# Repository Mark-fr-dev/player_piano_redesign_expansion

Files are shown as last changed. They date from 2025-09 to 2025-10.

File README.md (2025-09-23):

Player-Piano (FreeCAD Redesign and extension)

## Overview
This project is a **redesign of my earlier player-piano prototype**, moving from a wooden/acrylic build into a **parametric FreeCAD model** suitable for 3D printing.  
The aim is to create a **stable, modular frame** that can drive ~44 keys of a roll-up piano keyboard without “walking” across the surface. Later I plan to run it from a raspbery pi, which will ultimately be controlled via an AWS enabled server from an SAP HANA database.

- ✅ Open-source, parametric CAD design in **FreeCAD**  
- ✅ Modular approach: ~1 octave per frame section, bolted together  
- ✅ Arduino-driven servos (firmware in [separate repo](https://github.com/yourname/arduino-repo))  
- ✅ Documentation of design process via daily **lab notes**

---

## Project Goals
- Eliminate instability of the first prototype (prevent frame “walking”).  
- Create a **printable modular system** (1-octave units, chained to 44 keys).  
- Make the design **parameter-driven** (adjustable key pitch, frame spacing, servo layout).  
- Improve aesthetics and reproducibility (cleaner than the prototype).  

---

## Repository Structure
freecad/ # .FCStd parametric design files
stl/ # STL exports for 3D printing
notes/ # Daily lab notes in Markdown
images/ # Screenshots, diagrams, renders
README.md # Project overview (this file)

---

## Parameters (current baseline)
These are defined in a FreeCAD **Spreadsheet (Params)** and drive the master sketches:

| Parameter | Value | Notes |
|---|---|---|
| `white_pitch` | 23 mm | White key spacing |
| `octave_width` | 161 mm  | 7 × white_pitch |
| `piano_depth` | 161 mm  | Depth of active key area |
| `black_pitch_2` | 28 mm | 2-black-key group width |
| `black_pitch_3` | 27 mm | 3-black-key group width |
| `inter_black_pitch` | 39.5 mm | Gap between black groups |
| `full_frame_depth` | 220 mm  | Total module depth |
| `full_frame_height` | 180 mm  | Total module height |
| `servo_y_spacing` | 76.4 mm | Servo row spacing |

(See [/notes](notes/) for full parameter tables and daily updates.)

---

## Build Concept
- **Frame**: Each octave = base plate (XY) + side cheeks (YZ), joined by bolts/dowels.  
- **Servo bar**: Spanning between cheeks, aligned to white/black key offsets.  
- **Modularity**: 4 modules chained → 44 notes total.  
- **Fasteners**:  
  - Z-direction bolts: clamp stacked frame layers.  
  - X-direction bolts: join octaves side-to-side.  

---

## Previous Prototype
The original player-piano prototype was built using **wood and perspex, with Fusion 360 CAD**.  
Documentation (sketches and videos) is preserved in the repo: [player-piano (prototype)](https://github.com/yourname/player-piano).  

---

## Firmware
Servo driving software is maintained separately:  
👉 [arduino-player-piano](https://github.com/yourname/arduino-repo)  

---

## Progress Tracking
- Daily lab notes: [/notes](notes/)  
- Screenshots/renders: [/images](images/)  

---

## License
[MIT](LICENSE) — free to use, modify, and build upon.

---
=======
# player_piano_redesign_expansion
Redesign of my piano-player for 3D printing, raspberry pie and online song selection

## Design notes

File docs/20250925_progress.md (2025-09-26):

ChatGPT said:

Yes 👍 — I can see a few key things from our exchanges today that didn’t make it into your notes but would strengthen them. Here’s a refined draft with those items included:

# Piano Player Project — Daily Lab Notes
Date: 2025-09-25
Module: Piano bed and servo mounting structures

## Progress Today
- Reworked Params spreadsheet for tidiness; grouped parameters by category (keys, frame, servos, fasteners).
- Confirmed all parameters have aliases, so reordering won’t break references.
- Added horizontal positioning (dowel) holes to the "piano_bed" for alignment.
- Adjusted overall bedplate dimensions to fit within Prusa i3 build volume (250 × 210 × 210).
- Captured servo dimensions for SG90 profile and began setting up servo mounting geometry.
- Started decreasing material volume by adding pockets into the piano bed to reduce print time and filament cost.
- Started design of servo base plate, initially 3 mm thick, with awareness of balancing stiffness vs. print time.
- Discussed print-time/material tradeoffs (full plate ≈ 9 h vs ribbed/segmented ≈ 4–5 h).
- Confirmed workflow preference: add fillets as 3D features later in the tree, not inside sketches, for efficiency and robustness.
- Learned multiple ways to array cutouts (Sketcher Array, Part Design Linear Pattern, Draft Array).

## Next Steps
- Add vertical locating holes for stacking stability between layers.
- Test 3 mm servo base plate with ribs or flanges instead of pure thickness to save print time.
- Create parametric array of servo cutouts driven by `white_pitch`.
- Produce small coupon print (bolt + dowel cluster) to validate tolerances (~0.2 mm).
- Add fillet features at the end of body history for edges/pads.

## Design Notes (high-level rationale)
- One global Params spreadsheet will be used, with grouping by function (Keys, Frame, Servos, Fasteners). Local part-specific values can be added in separate sections.
- Dowels handle positioning, bolts handle clamping; clear separation of function improves assembly repeatability.
- Large flat plates risk long print times and wasted filament; ribbing strategy adopted to reduce cost/time while maintaining stiffness.
- Servo mounting will be split into two servo bars (white-key servos, black-key servos), both mounted to the servo base plate.
- Fillets applied at the feature level for cleaner sketches and easier future edits.

## File Updates
- Params.FCStd (spreadsheet restructured, all aliases set)
- Piano_bed.FCStd (added dowel holes, initial volume-reduction pockets)
- Servo_base_plate.FCStd (initial sketch, 3 mm thickness)

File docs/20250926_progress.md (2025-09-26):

# Piano Player Project — Daily Lab Notes
Date: 2025-09-25
Module: Piano_bed, Servo_plate, White_servo_bar

## Progress Today
- Completed lightening holes in the Piano_bed (circular array, parametric diameter/spacing).  
  → Purpose: reduce material volume and print time while maintaining stiffness.  
- Finalized horizontal and vertical bolt holes, dowel positioning holes, and push pads on the Piano_bed.  
- Completed Servo_plate with:  
  - Shaft holes for push rods.  
  - Mount holes and bosses for alignment.  
  - Servo mount tab slots sized for SG90 geometry.  
- Began White_servo_bar design:  
  - Captured key pitch from global parameters.  
  - Established initial spacing for servo cutouts.  
- Considered trade-off between custom lightening pockets (triangles) vs. simpler arrays (circles/rectangles) → settled on circular cutouts for efficiency and strength.  
- Reviewed FreeCAD workflow for arrays (Sketcher array vs Part Design Linear Pattern).  
- Confirmed strategy to keep sketches simple, with fillets and chamfers applied later as features.

## Next Steps
- Finish White_servo_bar geometry (servo slot dimensions, mounting holes).  
- Create Black_servo_bar with parametric offset relative to white keys.  
- Add vertical locating holes to Piano_bed for module stacking.  
- Test 3 mm plate + lightening holes vs ribbed reinforcement for print time/strength balance.  
- Export small coupon print (servo slot + boss + dowel) to test tolerances before full module print.

## Design Notes (high-level rationale)
- Lightening holes: chosen as circular for simplicity, robustness, and faster sketch/solve times compared to triangular pockets.  
- Bosses added to Servo_plate to strengthen mounting points for M5 screws.  
- Servo tab slots dimensioned from captured SG90 geometry (servo_width, servo_depth).  
- Servo mounting structure divided into White_servo_bar and Black_servo_bar to match key grouping, simplifying assembly and reducing print failures.  
- Parameter spreadsheet updated to drive new features consistently (bolt diameters, servo offsets, pitch).  

## File Updates
- Piano_bed.FCStd (added lightening holes, dowels refined).  
- Servo_plate.FCStd (completed shaft holes, bosses, tab slots).  
- White_servo_bar.FCStd (initial sketch started).

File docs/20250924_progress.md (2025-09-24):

# Piano Player Project — Daily Lab Notes
Date: 2025-09-24
Module: Piano Bed (1 Octave)

## Progress Today
- Designed the bedplate for one octave.
- Integrated horizontal and vertical bolt holes for fastening modules together.
- Added horizontal locating holes (dowels) for precise alignment.
- Added reinforced pads to transmit the piano push forces directly into the table surface, reducing stress on the frame.
- Confirmed overall geometry fits FreeCAD parametric structure.

## Next Steps
- Add vertical locating holes (to align stacked parts or cheek frames).
- Create white_key_bar and black_key_bar
- Create servo_base
- Work on the servo plate on which all the servos will be mounted

## Design Notes (high-level rationale)
- Pads: Avoid frame "walking" by transferring force vertically downward into the table.
- Dowels: Ensure repeatable alignment across octaves. Bolts handle clamping, dowels handle positioning.
- Dual fastening (horizontal + vertical): Supports both side-to-side chaining of octaves and vertical stacking of layers.
- Structure left simple for now — honeycomb infill will be handled by the slicer, not modeled in FreeCAD.

## File Updates
- Piano_bed.FCStd → new baseplate geometry.
- Design notes document updated with part-level rationale.

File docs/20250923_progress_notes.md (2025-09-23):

# 🎹 Piano Player Project — Lab Notes
**Date:** 2025-09-23  
**Author:** Mark de Villiers  

---

## Objective
Redesign the piano player mechanism to be **more stable** (prevent “walking” on the rubber keyboard), improve appearance, and prepare for a **3D-printed modular version**. The long-term aim is to achieve a rigid, reliable structure that can be printed at low cost and assembled in modules (≈1 octave each).

---

## Activities Today
- **Transitioned CAD tools**  
  - Began learning **FreeCAD** as an alternative to Fusion 360 (too expensive).  
  - Learned FreeCAD basics: creating sketches, pads, referencing planes, and capturing geometry.  

- **Captured baseline geometry**  
  - Modeled the prototype piano player frame (current dimensions).  
  - Confirmed the approximate overall size; unlikely to reduce footprint significantly, but improvements in **rigidity and aesthetics** are achievable.  

- **Parameterization**  
  - Created initial design parameters for keys, frame, and servos.  
  - Verified octave width, white/black key spacing, and depth relations.  

- **Next steps**  
  - Integrate these parameters into a FreeCAD **Spreadsheet** for parametric design.  
  - Begin modular design (1-octave frame with side cheeks, servo bar, and base plate).  
  - Test ShapeBinders to propagate master sketches into Bodies.  

---

## Parameters Defined
| Parameter | Value | Notes |
|---|---|---|
| `white_pitch` | 23 mm | White key spacing |
| `octave_width` | 161 mm | 7 × white_pitch |
| `piano_depth` | 161 mm | Depth of piano key area |
| `key_depth` | 131 mm | Active depth of white keys |
| `black_pitch_2` | 28 mm | Spacing for 2-black-key group |
| `black_pitch_3` | 27 mm | Spacing for 3-black-key group |
| `inter_black_pitch` | 39.5 mm | Gap between black key groups |
| `black_key_width` | 12 mm | Nominal width of black key |
| `white_key_width` | 20.5 mm | Nominal width of white key |
| `black_key_depth` | 80 mm | Depth of black key |
| `full_frame_depth` | 220 mm | Total depth of module |
| `full_frame_height` | 180 mm | Total height of module |
| `edge_offset` | 15 mm | Bolt hole offset |
| `rubber_height_clearance` | 15 mm | Rubber key + 5 mm clearance |
| `base_thickness` | 20 mm | Printed base plate |
| `shaft_length` | 125 mm | Servo shaft length requirement |
| `servo_travel` | 10 mm | Actuator stroke |
| `top_thickness` | 5 mm | Printed top plate |
| `servo_y_spacing` | 76.4 mm | Spacing between servo rows |

---

## Reflections
- FreeCAD is different from Fusion 360 but already feels workable for this project.  
- The prototype size may stay similar, but **parametric modeling** will let me refine structure, tolerances, and servo alignment.  
- The focus now is **rigidity + modularity** (1-octave units that bolt together cleanly).  

---

## Next Steps
- Build **Spreadsheet (Params)** in FreeCAD with the values above.  
- Create **master sketches** (XY for footprint, ZY for cheeks, bolt hole references).  
- Experiment with **ShapeBinders** to reuse sketches across Bodies.  
- Print a **test plate** with bolt holes to check tolerances (M3/M5, dowels).  
- Draft servo bar design: use `servo_y_spacing` + `white_pitch` to test array of cutouts.  

---

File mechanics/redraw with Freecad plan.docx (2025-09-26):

1. Create a new document & structure

- Open FreeCAD → File → New.
- In Part Design workbench:
  - Create a Part container (name: Piano_ModularFrame).
  - Inside, create a Body (name: Master_Body).
  - This will hold your master geometry (keyboard outline, bolt pattern, reference planes).

2. Master sketch (parametric skeleton)

- In Master_Body, create a new Sketch on the XY plane.
- Draw:
  - A rectangle for the keyboard footprint per octave (about 164 mm × ~120 mm deep).
  - Add construction lines for note spacing (12 equal divisions along width).
  - Add 2–3 circles outside edges → bolt holes for module joining.
- Constrain dimensions with named parameters:
  - octave_width = 164 mm
  - depth = 120 mm
  - bolt_spacing = 80 mm (Tip: put them in the Spreadsheet workbench, link dimensions → makes edits easy later).

3. Derive module bodies

- For each part (side rail, top rib, actuator bar, clamp jaws), create a new Body.
- Use ShapeBinder to pull in the master sketch references (keyboard outline, bolt holes).
- Build features relative to these, so changes propagate.

Examples:

- Side Rail:
  - Sketch profile (L-shaped or ribbed beam) along the side.
  - Pad to full depth.
- Top Plate / Rib:
  - Sketch on XY → pad 5–6 mm.
  - Add cutouts for servo bar and wiring.
- Servo Bar:
  - Long rectangular beam across module width.
  - Add pockets for servos (20×12 mm typical for micro SG90 class).
- Clamps:
  - Small pads on the side edges of the footprint rectangle.
  - Sketch → pad up → fillet corners.

4. Assembly interfaces

- On each side face of the module, extrude small alignment bosses (Ø 6 mm).
- Matching recess on the opposite side.
- Add 2× through bolt holes (M5 clearance = 5.5 mm) per side.
- This ensures rigid alignment when bolting modules together.

5. Printing considerations

- Split tall parts (side cheeks) if they exceed your 210 mm Z.
- Design ribs and cutouts so modules are light but stiff.
- Add nut traps for bolts:
  - M3/M5 hex pockets undersized by ~0.2 mm.
- Tolerances:
  - Sliding fit: +0.3 mm clearance.
  - Alignment pins: oversize hole by +0.1–0.2 mm, ream after printing.

6. Parametric array & partial module

- Use Draft Array or Assembly4 workbench to copy the module 6×.
- For the last module (44 notes total), suppress 4 keys (partial).

7. Export for print

- Select each Body → File → Export → STL.
- Slice in PrusaSlicer. Print test pieces at low infill (10–15%) first to confirm fits.

✅ Suggested module contents

Each octave module includes:

- Frame (side rails + top/bottom ribs + bolt interface)
- Actuator bar with servo pockets (12 max)
- Clamps to hold roll-up piano edge
- Cable channels at rear
- Alignment bosses + bolt holes for chaining

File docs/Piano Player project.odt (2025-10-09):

SAP HANA project

# Piano electronics

## Get existing system working again

## Consider if upgraded PCB is worth the effort?

### Can fix jitter problems?

## redesign?

## Reassemble

## Re-fault check

# Raspberry Pi

## New software/packages that can do the following:

## Send midi sigs to Arduino

## Get data from arduino? What data? How?

## Get full songs from HANA?

## Send data to HANA, how? Which data?

# Piano mechanics

## Full redesign for 3D manufacture

## Remove 44 servos from existing half player

## Consider installing 44 new servos for complete system

# Piano software (Arduino Mega)

## Software will definitely need to be rewritten/modified

## Once the mechanics and electronics are stable once more

# HANA DB

## Send data to raspberry pi

## Recieve data from pi

# Simple website

## request songs to play on player

## View livestream of 1 or 2 cameras as the song plays.

## Display HANA data in a meaningful way

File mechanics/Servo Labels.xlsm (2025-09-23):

PN | 2 | PN | 25 | PN | 40 | PN | 2 | PN | 25 | PN | 40
SVN | 0 | SVN | 15 | SVN | 30 | SVN | 0 | SVN | 15 | SVN | 30
PN | 3 | PN | 26 | PN | 41 | PN | 3 | PN | 26 | PN | 41
SVN | 1 | SVN | 16 | SVN | 31 | SVN | 1 | SVN | 16 | SVN | 31
PN | 4 | PN | 27 | PN | 42 | PN | 4 | PN | 27 | PN | 42
SVN | 2 | SVN | 17 | SVN | 32 | SVN | 2 | SVN | 17 | SVN | 32
PN | 5 | PN | 28 | PN | 43 | PN | 5 | PN | 28 | PN | 43
SVN | 3 | SVN | 18 | SVN | 33 | SVN | 3 | SVN | 18 | SVN | 33
PN | 6 | PN | 29 | PN | 44 | PN | 6 | PN | 29 | PN | 44
SVN | 4 | SVN | 19 | SVN | 34 | SVN | 4 | SVN | 19 | SVN | 34
PN | 7 | PN | 30 | PN | 45 | PN | 7 | PN | 30 | PN | 45
SVN | 5 | SVN | 20 | SVN | 35 | SVN | 5 | SVN | 20 | SVN | 35
PN | 8 | PN | 31 | PN | 46 | PN | 8 | PN | 31 | PN | 46
SVN | 6 | SVN | 21 | SVN | 36 | SVN | 6 | SVN | 21 | SVN | 36
PN | 9 | PN | 32 | PN | 47 | PN | 9 | PN | 32 | PN | 47
SVN | 7 | SVN | 22 | SVN | 37 | SVN | 7 | SVN | 22 | SVN | 37
PN | 10 | PN | 33 | PN | 48 | PN | 10 | PN | 33 | PN | 48
SVN | 8 | SVN | 23 | SVN | 38 | SVN | 8 | SVN | 23 | SVN | 38
PN | 11 | PN | 34 | PN | 49 | PN | 11 | PN | 34 | PN | 49
SVN | 9 | SVN | 24 | SVN | 39 | SVN | 9 | SVN | 24 | SVN | 39
PN | 12 | PN | 35 | PN | 50 | PN | 12 | PN | 35 | PN | 50
SVN | 10 | SVN | 25 | SVN | 40 | SVN | 10 | SVN | 25 | SVN | 40
PN | 13 | PN | 36 | PN | 51 | PN | 13 | PN | 36 | PN | 51
SVN | 11 | SVN | 26 | SVN | 41 | SVN | 11 | SVN | 26 | SVN | 41
PN | 22 | PN | 37 | PN | 52 | PN | 22 | PN | 37 | PN | 52
SVN | 12 | SVN | 27 | SVN | 42 | SVN | 12 | SVN | 27 | SVN | 42
PN | 23 | PN | 38 | PN | 53 | PN | 23 | PN | 38 | PN | 53
SVN | 13 | SVN | 28 | SVN | 43 | SVN | 13 | SVN | 28 | SVN | 43
PN | 24 | PN | 39 |  |  | PN | 24 | PN | 39
SVN | 14 | SVN | 29 |  |  | SVN | 14 | SVN | 29

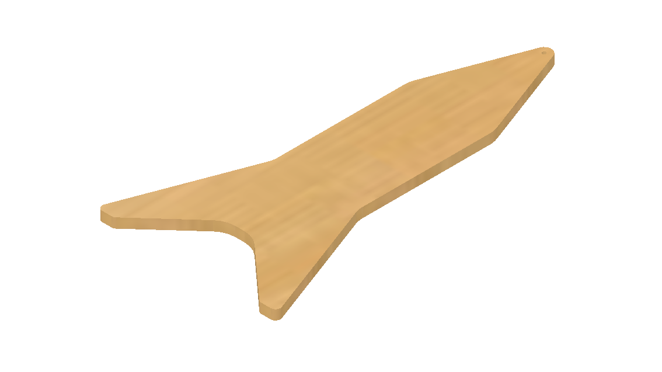
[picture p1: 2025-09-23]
mechanics/Laser Cutting/Rocket v4.png

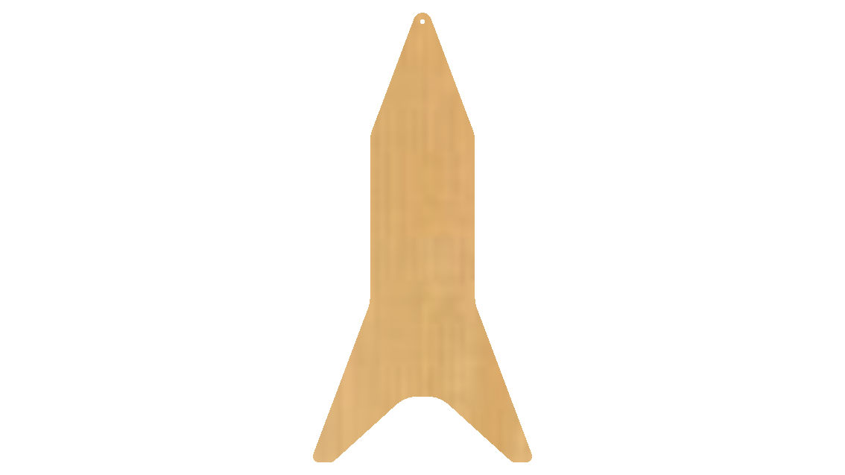
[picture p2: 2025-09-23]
mechanics/Laser Cutting/Rocket v4 front.png

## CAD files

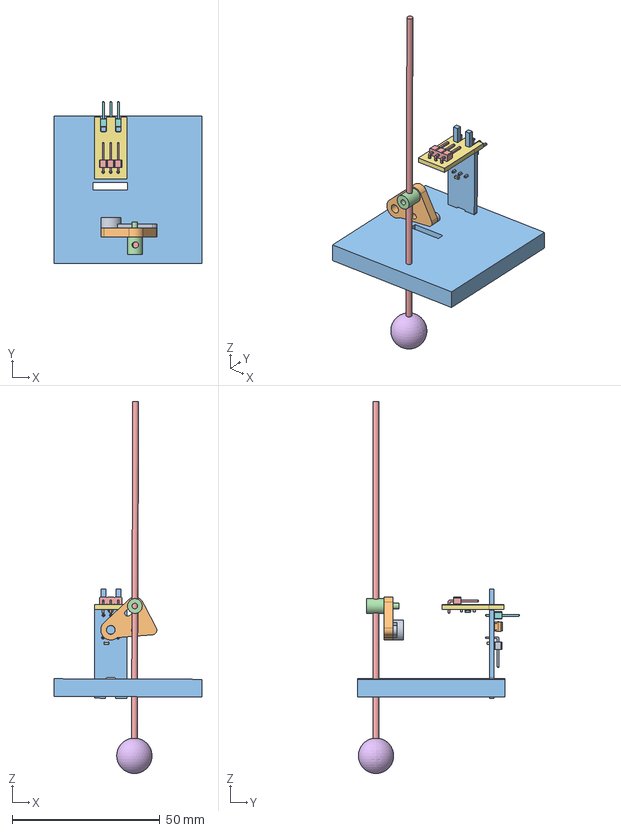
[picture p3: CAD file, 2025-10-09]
mechanics/Piano_Modular_Frame/Servo_asm.FCStd
50.0 x 54.9 x 126.0 mm
servo arm v4
Servo Slider Arm
Base
Servo-shaft connector
Push Shaft
Pusher Ball
C_0603_1608Metric
PinHeader_1x03_P2
PinHeader_1x03_P2 (1)
TAJC107K010TNJ
MCP9700T-H_LT
PinHeader_1x03_P003
C_0603_1608Metric001 x 2

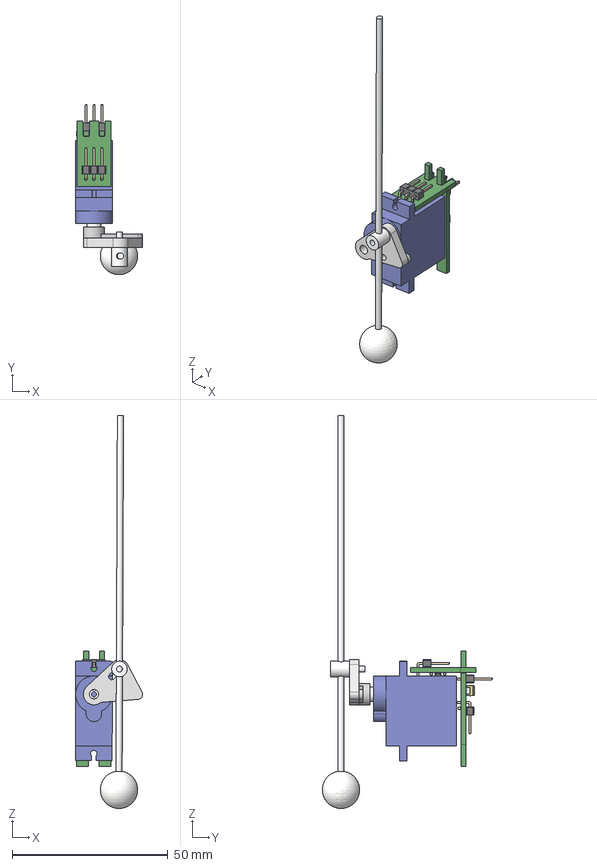
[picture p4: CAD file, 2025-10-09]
mechanics/imported_fusion/Servo_Assembly_For_Black_Keys.stp
21.6 x 54.6 x 126.0 mm
servo arm
Servo Motor SG90
Servo Slider Arm
Servo-shaft connector
Push Shaft
Pusher Ball

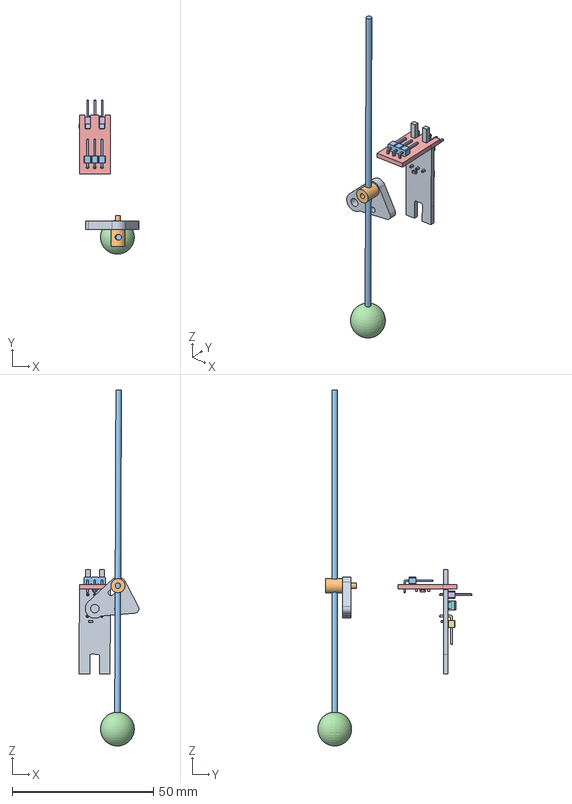
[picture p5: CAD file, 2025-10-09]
mechanics/Piano_Modular_Frame/SG90_servo_assembly.FCStd
21.2 x 54.6 x 126.0 mm
Servo Slider Arm
Servo-shaft connector
Push Shaft
Pusher Ball
C_0603_1608Metric
PinHeader_1x03_P2
PinHeader_1x03_P2 (1)
TAJC107K010TNJ
MCP9700T-H_LT
PinHeader_1x03_P003
C_0603_1608Metric001 x 2

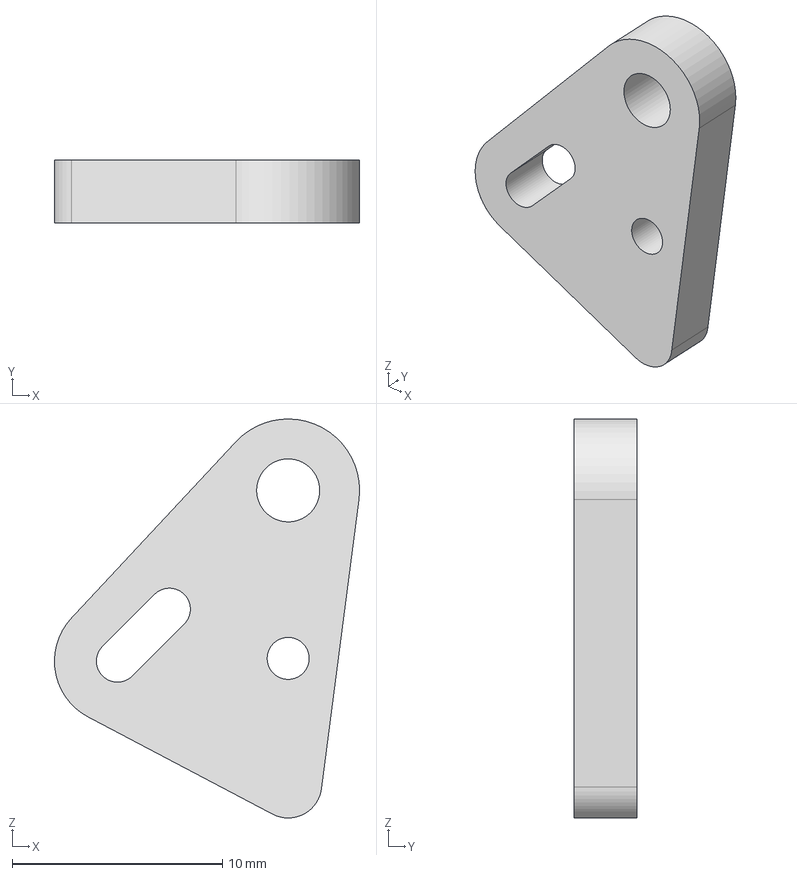
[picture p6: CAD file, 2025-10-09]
mechanics/imported_fusion/Servo+Assembly_Servo+Slider+Arm.stp
14.5 x 3.00 x 19.0 mm

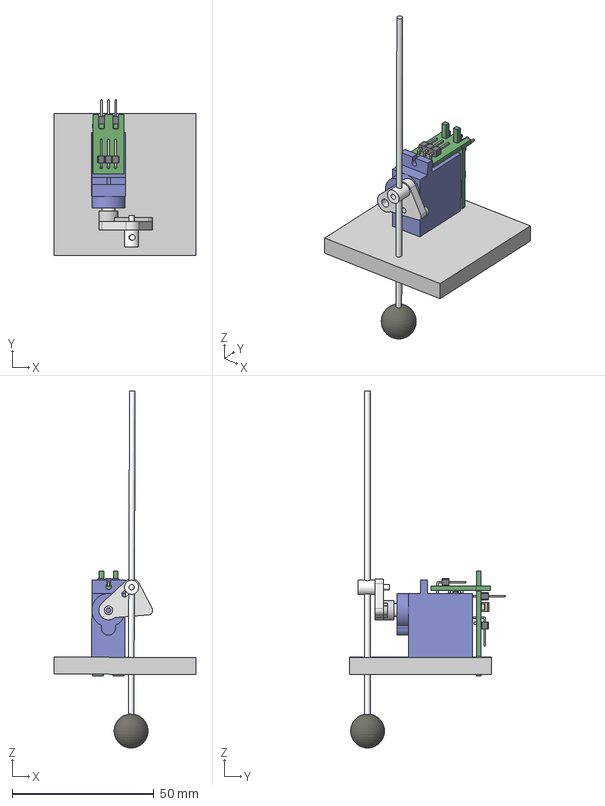
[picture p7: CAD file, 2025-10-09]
mechanics/imported_fusion/Servo+Assembly.stp
50.0 x 54.9 x 126.0 mm
servo arm
Servo Motor SG90
Servo Slider Arm
Base
Servo-shaft connector
Push Shaft
Pusher Ball

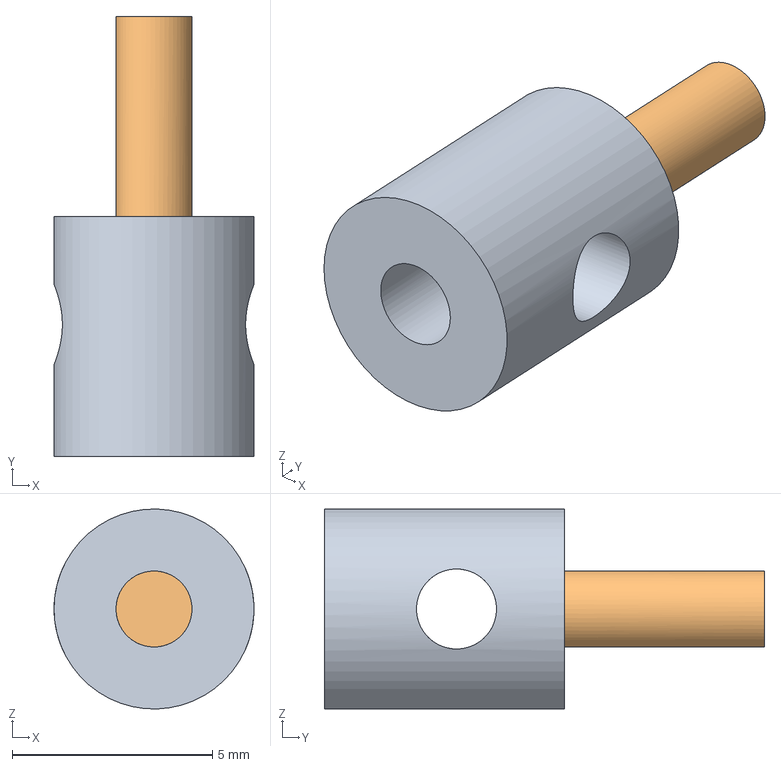
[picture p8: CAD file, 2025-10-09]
mechanics/imported_fusion/Prt_+Servo+Assembly_Servo-shaft+connector.stp
5.00 x 11.0 x 5.00 mm

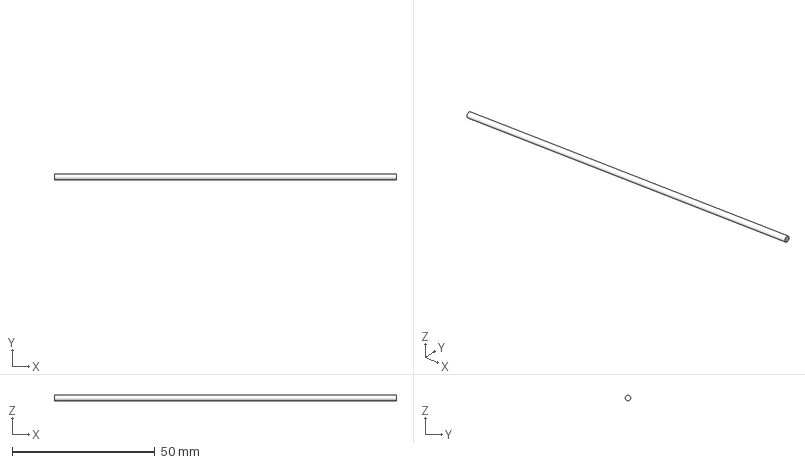
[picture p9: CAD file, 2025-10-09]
mechanics/imported_fusion/Prt_+Servo+Assembly_Push+Shaft.stp
120.0 x 2.00 x 2.00 mm

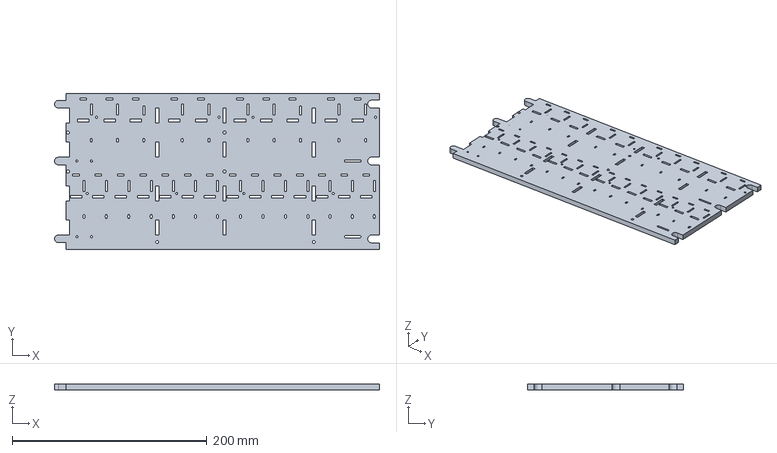
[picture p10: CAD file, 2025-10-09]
mechanics/Drawings/Piano_Modular_Frame.FCStd
334.0 x 160.0 x 6.00 mm

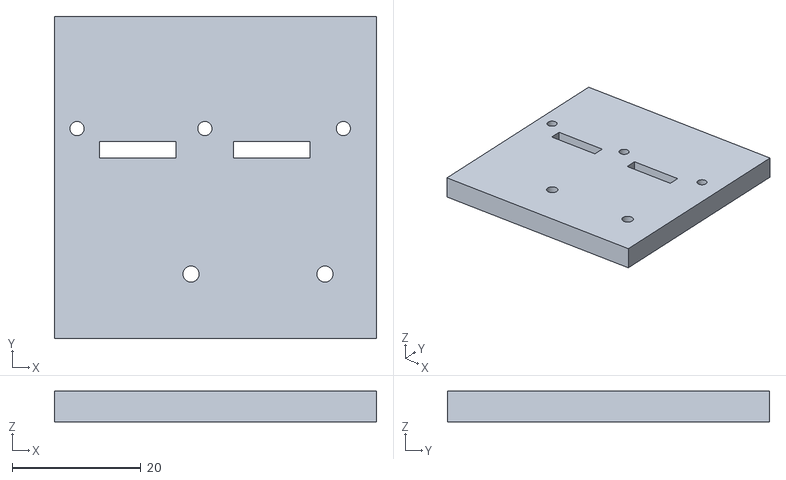
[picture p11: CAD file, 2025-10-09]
mechanics/For 3D printing/Test_mount_2-Master_bodyServo_base.stl
50.0 x 50.0 x 4.80

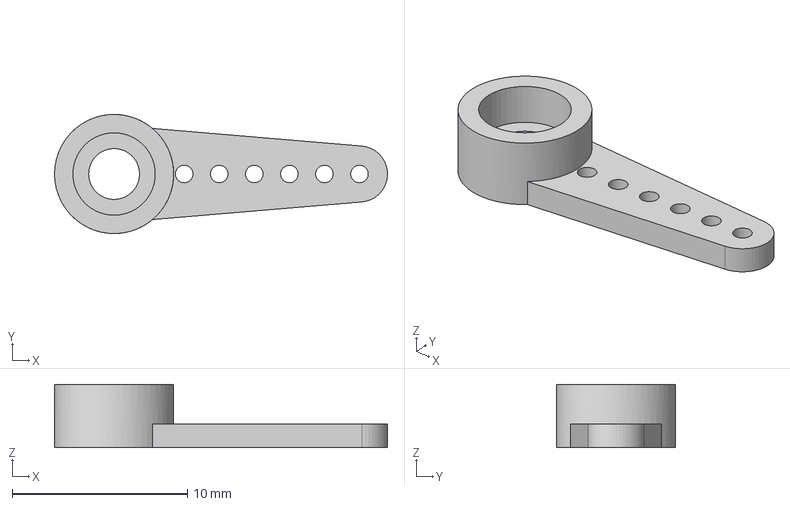
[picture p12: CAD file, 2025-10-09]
mechanics/imported_fusion/servo+arm.stp
19.0 x 6.80 x 3.60 mm

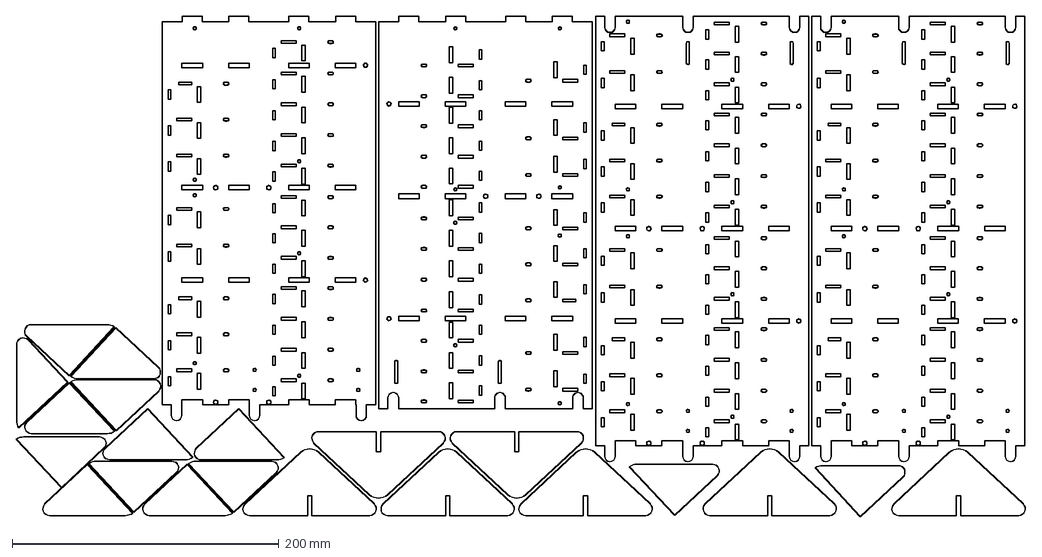
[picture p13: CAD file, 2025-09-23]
mechanics/Laser Cutting/6mm Wood Mark de Villiers.dxf
757.2 x 375.3 mm

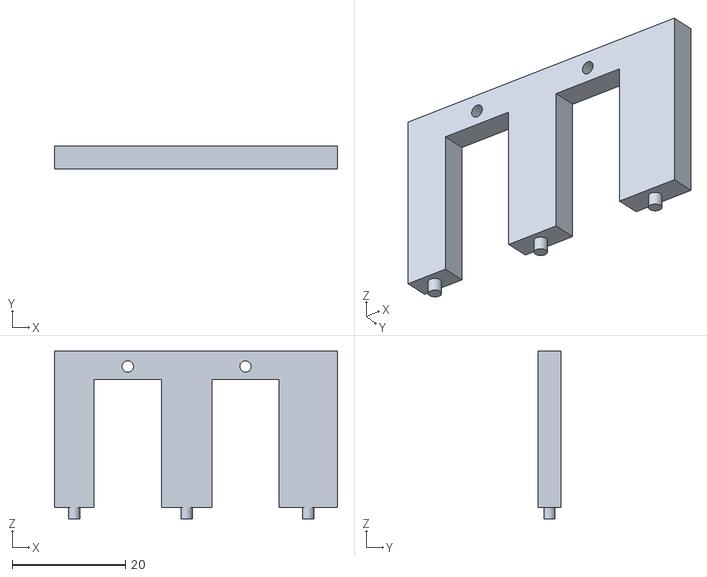
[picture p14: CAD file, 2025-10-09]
mechanics/For 3D printing/Test_mount_2-Master_bodyServo_hold_down.stl
50.0 x 4.00 x 29.6

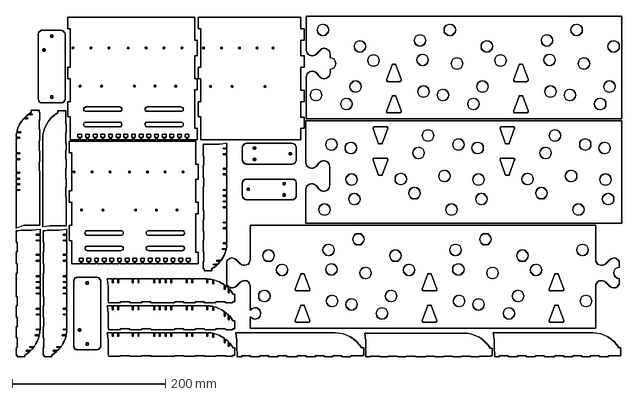
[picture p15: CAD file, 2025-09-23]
mechanics/Laser Cutting/3mm - 2 - Mark de Villiers acrylic.dxf
791.4 x 445.2 mm

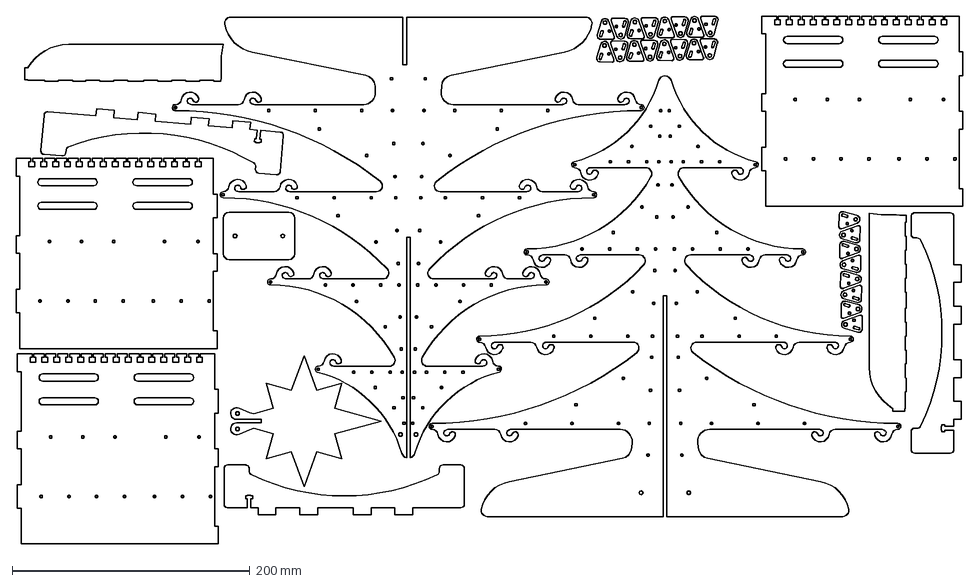
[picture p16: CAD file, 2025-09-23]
mechanics/Laser Cutting/3mm - 3 - Mark de Villiers acrylic.dxf
795.7 x 443.9 mm

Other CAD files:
mechanics/Piano_Modular_Frame/Servo_assembly.FCStd
mechanics/Piano_Modular_Frame/Test_mount.FCStd
mechanics/Laser Cutting/Circles.dxf
mechanics/Piano_Modular_Frame/servo_hold_down_clip.FCStd
mechanics/Laser Cutting/3mm - 1 - Mark de Villeirs acrylic.dxf
mechanics/Laser Cutting/4mm Engraving.dxf
mechanics/Laser Cutting/4mm Wood Cut 2 Mark de Villiers.dxf
mechanics/Laser Cutting/4mm Wood Cut 2 V2.dxf
mechanics/Laser Cutting/4mm Wood Cut 2.dxf
mechanics/Laser Cutting/4mm Wood Mark de Villiers.dxf
mechanics/Laser Cutting/4mm Wood cut 2 V4.dxf
mechanics/Laser Cutting/5mm - 1 - Mark de Villiers acrylic.dxf
mechanics/Laser Cutting/5mm cut 1 v3.dwg
mechanics/Laser Cutting/Laser Cut 6mm cut 1.dxf
mechanics/Laser Cutting/Laser Cut 6mm cut 2.dxf
mechanics/Laser Cutting/Wood Rocket outline.dxf
mechanics/Old Drawings/Keyboard Layout.FCStd
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

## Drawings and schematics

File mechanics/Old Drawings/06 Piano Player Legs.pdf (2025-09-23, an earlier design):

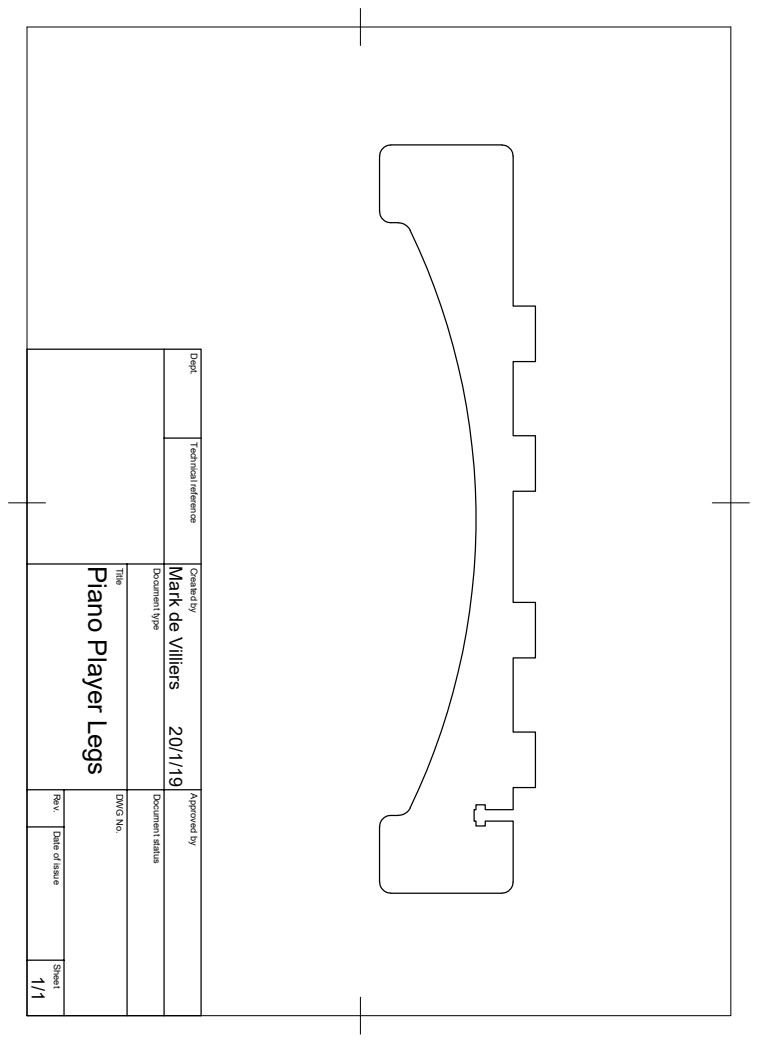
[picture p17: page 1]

Dept. Technical reference Created by Approved by Title DWG No. Document type Document status Rev. Date of issue Sheet 20/1/19 1/1 Piano Player Legs Mark de Villiers

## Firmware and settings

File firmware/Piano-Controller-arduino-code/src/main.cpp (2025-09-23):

#include <Arduino.h>
#include <Servo.h>
//#include <MIDI.h>
#include <EEPROM.h>
//#include <midi_RingBuffer.h>
//#include <midi_Namespace.h>
/*
26/12/2019
Still struggling to get this working well for the high note. I put some of the
setup code into functions and now it doesn't work at all. Grr
 */

//22/12/2019
/*
Adding a ringbuffer to store incoming data better
See http://fortyseveneffects.github.io/arduino_midi_library/a00064.html
 */
// 24/03/2019
/* Piano Player revision 1.0 using code from Mike Cook's
  book to speed up my MIDI handling

  Also changing some of the funtions to use pointers

  receives midi signals plays them to
  piano independent of high or low notes of the piano
 */

#include "pitches.h"
#include "servos.h"
#include "controller.h"
//#include "midihandling.h"
//#define DEBUG_SERVO
//#define DEBUG_HANDLES
//#define DEBUG_BUFF

//#define SETUPEEPROM
//#define DEBUG_MIDI
//-----IO Pins -------
//static const int high_led = A0;  // LED displaying a NoteOn received
static const int diag_led = A2;   //LED used for simple diagnostics
//static const int relay_pin = 16; //
//static const int del = 200; //delay
/*if connected to 5V via 10k Resistor denotes that this micro is controlling
    high notes
    If connected to 0V = low notes */
const static int note_sel  = 17;
//-----Servo variables -----
extern Servo my_servo[];  //An array of servos
extern byte servo_pin[]; //Servo Arduino pins
extern byte *ptr_to_trim;
bool piano_high_notes; //high or low side?
byte *ptr_wh_home;
byte *ptr_bl_home;
extern const int off_ang;
byte servo_num = 0;
// -----Midi variables -----
const static byte midi_highest_piano_note = 0x6E;  //This is the max midi piano note dec 108
const static byte midi_high_nt_ptch_offst = 0x41; // Lowest note code + 44 notes = decimal 65
const static byte midi_low_nt_ptch_offst  = 0x15; // Lowest midi piano note code = decimal 21
//MIDI_CREATE_INSTANCE(HardwareSerial, Serial3, midiSerial);
/*-------Note buffer for on and off-------*/
//typedef byte pitch_t;
//typedef byte vel_t;
typedef struct {
  byte pitch;
  byte velocity;
} note_t ;

#define SIZE_OF_BUFFER 32 // Space to store 16 notes SHOULD ALWAYS BE AN EVEN NUMBER
int circularBuff[SIZE_OF_BUFFER];
int bufferLength = 0;
int readIndex = 0;
int writeIndex = 0;

int count = 0;
int count2 = 0;
#define off_delay 3000
//-----Microphone variables -----
static const byte microph_ana = A1;  //Analogue output of microphone
static const byte calibrate_pin = A0; //pin to request calibration
static const byte microph_dig_int = 18;    //Digital output of microphone
volatile byte keyPressed;

byte incomingByte;
byte note;
byte velocity;

int statusLed = 13;   // select the pin for the LED

int action = 2; //0 =note off ; 1=note on ; 2= nada

//-----Function declarations-----
bool checkOut(void);
bool buff_is_empty(void);
bool write_buff(note_t note);
note_t read_buff(void);
void buff_clr(void);
//void write_buff(fifo_t note);
//fifo_t read_buff(void);
//void MyControlChange(byte channel, byte number, byte value);
////void MyHandleNoteOn(byte channel, byte pitch, byte velocity);
//void MyHandleNoteOff(byte channel, byte pitch, byte velocity) ;

void ISR_keyPress();
void FlashLED(byte flashes);
bool MustCal(void);
bool CheckHighLow(void);
void Calibrate(void);
void playNote(byte note, byte velocity);
//=======================================================================
void setup() {
  #ifdef DEBUG_SERVO
  Serial.begin(115200);

  Serial.println("-----Hello Arduino-----");

  #endif

  bool cal = false;
  //-----Setup Pins-----
  pinMode(diag_led,OUTPUT);
  //------Check calibrate pin
  //cal = MustCal();
  //-----Do we need to calibrate?------
  pinMode(calibrate_pin, INPUT_PULLUP);
  for(byte i = 0; i < 100; i++){ //check calibrate_pin for 2 seconds after startup
    bool cp = digitalRead(calibrate_pin); //switch pulls input down
    if(cp == LOW){
      cal = true;
      break;
    }
    delay(20);
  }
   //------Check High/Low side-----
  piano_high_notes = CheckHighLow();
  //------This Mask may make the servos jitter less -----

  //------set array pointers to the correct arrays (high/Low)
  setArrayPointers(piano_high_notes);

  //------Calibrate here-----
  if(cal == true){
    Calibrate();
  }
  //------Now we can attach the servos------
  //TIMSK0 = 0;
  servoAttach();   //Attach to servos here

  //If the EEPROM has not been initialised correctly, then run this
  #ifdef SETUPEEPROM
  for(byte i = 0; i < num_servos; i++){
    Serial.print("Servo: ");
    Serial.print(i);
    Serial.print("---Angle: ");
    Serial.println(int(*(ptr_to_trim + i)));
  }
  #endif
  //------Clear the note buffer------
  //void buff_clr(void);
  //------Setup MIDI-----
  /*midiSerial.begin(MIDI_CHANNEL_OMNI);
//  midiSerial.setInputChannel(1);
  //midiSerial.turnThruOff();
  midiSerial.setHandleControlChange(MyControlChange);
  midiSerial.setHandleNoteOn(MyHandleNoteOn);
  midiSerial.setHandleNoteOff(MyHandleNoteOff);
  Serial.println("\t--- Midi is set up ----");*/

  #ifdef SETUPEEPROM
  for(byte i = 0; i < num_servos; i++){
      Serial.print("EEPROM value: \t");
      Serial.print(i);
      Serial.print("\t is: \t");
      Serial.println(EEPROM.read(i));
  }
  #endif
    Serial3.begin(31250);
}
//=============================================================================
void loop() {
   //midiSerial.read();
   //checkOut();
   count++;
   if (Serial3.available() > 0) {
      //count = 0;
       // read the incoming byte:
       incomingByte = Serial3.read();
       //Serial.print("Serial 3 byte\t");
       //Serial.println(incomingByte);
       // wait for as status-byte, channel 1, note on or off
       if (incomingByte == 144) { // CH1 note on message starting starting
         note = Serial3.read();
         velocity = Serial3.read();
         playNote(note, velocity);
         return;
       } else if (incomingByte == 128) { //CH1 note off message starting
         note = Serial3.read();
         playNote(note,0);
         return;
       } else if (incomingByte == 255) { // control change message
         servoHome();
         return;
         //not implemented yet
       } else if ((action == 0) && (note == 0)) { // if we received a "note off", we wait for which note (databyte)
         note = incomingByte;
         playNote(note, 0);
         note = 0;
         velocity = 0;
         action = 2;//now waiting for another noteOn or noteOff
         return;
       } else if ((action == 1) && (note == 0))
       { // if we received a "note on", we wait for the note (databyte)
         note = incomingByte;
         return;
       } else if ((action == 1) && (note != 0))
       { // ...and then the velocity
         velocity = incomingByte;
         playNote(note, velocity);
         note = 0;
         velocity = 0;
         action = 2; // waiting for
         return;
       }
       else if ((action == 3) && (incomingByte == 123))
       {
         servoHome();
         action = 2;
         return;
       } else if (incomingByte == 176) { // control change message
         return;
         //not implemented yet
       } else if (incomingByte == 208) { // aftertouch message starting
         return;//not implemented yet
       } else if (incomingByte == 160) { // polypressure message starting
         return;//not implemented yet
       } else {
         return;//nada
       }
     }

     /*if(count == 10000)
     {
       count = 0;
       count2++;
       if(count2 == 1000){
       servoHome();
       count2 = 0;
      }

    }*/
}
void playNote(byte note, byte velocity) {
  //Serial.println("In PlayNote");
  /*int value = LOW;
  if (velocity > 10) {
    value = HIGH;
  } else {
    value = LOW;
  }*/
  if(!piano_high_notes){
      if (note > midi_low_nt_ptch_offst && note < midi_high_nt_ptch_offst) {
        servoWrite(note - midi_low_nt_ptch_offst, velocity);
        return;
    }else{
      return;
    }
  }else if (piano_high_notes){
    if(note >= midi_high_nt_ptch_offst && note < midi_highest_piano_note){
      servoWrite(note - midi_high_nt_ptch_offst, velocity);
      return;
      //Serial.println("Playing a high note");
    }else{
      return;
    }
  } else {return;}
}

/*****
  Purpose: Calibrate servos by pressing each key individually
  Parameter List:
        none
  Return value:
        none
 *****/
void Calibrate(void){
  #ifdef DEBUG_SERVO
  Serial.println("\tIn Calibrate()");
  #endif
  pinMode(microph_dig_int, INPUT_PULLUP);
    attachInterrupt(digitalPinToInterrupt(microph_dig_int), ISR_keyPress, RISING);
    servoTrimInit();
    detachInterrupt(digitalPinToInterrupt(microph_dig_int));
    return;
}
/*****
  Purpose: Check if this controller plays the high octaves or low octaves
  Parameter List:
        none
  Return value:
        bool oct  true - high notes
                  false - low notes
 *****/
bool CheckHighLow(void){
  #ifdef DEBUG_SERVO
  Serial.println("\tIn CheckingHL()");
  #endif
  bool ret;
  pinMode(note_sel, INPUT_PULLUP);
  ret = (bool)digitalRead(note_sel);  //Select High or low side of the piano
  Serial.print("\tPlaying the ");
  if(ret)
    Serial.print("high ");
  else
    Serial.print("low ");
  Serial.println("notes");
  return ret;
}
/*****
  Purpose: Check if the Calibrate key has been pressed for 2 seconds after a restart
  Parameter List:
        none
  Return value:
        bool cal  true - calibrate
                  false - do nothing
 *****/
bool MustCal(void){
#ifdef DEBUG_SERVO
  Serial.println("\tIn MustCal()");
#endif
  //-----Do we need to calibrate?------
  pinMode(calibrate_pin, INPUT_PULLUP);
  for(byte i = 0; i < 100; i++){ //check calibrate_pin for 2 seconds after startup
    bool cp = digitalRead(calibrate_pin); //switch pulls input down
    if(cp == LOW){
      return true;
      break;
    }
    delay(20);
  }
  return false;
}
/*****
  Purpose: Check for a piano keypress via microphone.
            Sets keyPressed to HIGH
  Parameter List:
        none
  Return value:
        void
 *****/
void ISR_keyPress(){
  keyPressed = HIGH;
//  FlashLED(2);
}
/*****
  Purpose: Flash diagnostic LED 'flashes' number of times
  Parameter List:
        byte flashes  number of times that must be flashed
  Return value:
        void
 *****/
 void FlashLED(byte flashes)
 {
   for(int i =0 ; i < flashes ; i++)
   {
     digitalWrite(diag_led,HIGH);
     delay(200);
     digitalWrite(diag_led,LOW);
     delay(200);
   }
 }
/*****
 Purpose: Check midi control change commands. Panic or all notes off can
             be sent via this command
            For definition see midi_Defs.h
 Parameter List:
         byte channel  command channel
         byte number  what is the command number
         byte value   the command value - not used for control change
 Return value:
         void
 *****/
/*void MyControlChange(byte channel, byte number, byte value){
  switch(number){
    case 120: case 121: case 123:
      servoHome(); //send all servos home
      buff_clr(); //start the buffer again
      return;
    default:
      return;
  }
}*/
/*****
 Purpose: MyHandleNoteON is the function that will be called by the Midi Library
          when a MIDI NOTE ON message is received.
          This command will be buffered for later execution.
          For definition see midi_Defs.h
 Parameter List:
         byte channel  command channel
         byte pitch     which piano key?
         byte velocity  This should be zero for note off
 Return value:
         bool         indicating successful addition to the buffer
 *****/
/*void MyHandleNoteOn(byte channel, byte pitch, byte velocity) {
  #ifdef DEBUG_HANDLES
  Serial.print("\t\tON--Ch ");
  Serial.print(channel);
  Serial.print("\tptch ");
  Serial.print(pitch);
  Serial.print("\tvel ");
  Serial.println(velocity);
  #endif
  if(channel >= 4){ //piano should be received on these channels
    #ifdef DEBUG_HANDLES
    Serial.println("ON wrong chan");
    #endif
    return;
  }else if(pitch  >= midi_highest_piano_note){ //piano should be received on these channels
    #ifdef DEBUG_HANDLES
    Serial.println("ON note2high");
    #endif
    return;
  }else if(pitch  <  midi_low_nt_ptch_offst){   //not a note this piano can play
    #ifdef DEBUG_HANDLES
    Serial.print("ON note2low\t");
    Serial.println(pitch);
    #endif
    return;
  }else if(piano_high_notes && (pitch < midi_high_nt_ptch_offst)){ //not a note for the high controller
    #ifdef DEBUG_HANDLES
    Serial.println("ON note4lowKeys");
    #endif
    return;
  }else if(!piano_high_notes && (pitch >= midi_high_nt_ptch_offst)){
    #ifdef DEBUG_HANDLES
    Serial.println("ON note4highKeys");
    #endif
    return;
  }
  note_t this_note;
  this_note.pitch = pitch;
  this_note.velocity = velocity;
  #ifdef DEBUG_HANDLES
  Serial.print("N/On Buffwrite p ");
  Serial.print(pitch);
  Serial.print(" v ");
  Serial.println(velocity);
  #endif
  if(write_buff(this_note)){
      return;
  } else {
    Serial.println("Buff++"); //buffer is full
      return;
  }
}*/


/*****
 Purpose: MyHandleNoteOFF is the function that will be called by the Midi Library
          when a MIDI NOTE OFF message is received.
          This command will be buffered for later execution.
          For definition see midi_Defs.h
 Parameter List:
         byte channel  command channel
         byte pitch     which piano key?
         byte velocity  This should be zero for note off
 Return value:
         bool   indicating successful addition to the buffer
 *****/
/*void MyHandleNoteOff(byte channel, byte pitch, byte velocity) {
  #ifdef DEBUG_HANDLES
  Serial.print("\t\tOFF--Ch ");
  Serial.print(channel);
  Serial.print("\tptch ");
  Serial.print(pitch);
  Serial.print("\tvel ");
  Serial.println(velocity);
  #endif

  if(channel >= 4){ //piano should be received on these channels
    #ifdef DEBUG_HANDLES
    Serial.println("OFF wrong chan");
    #endif
    return;
  }
  else if(pitch  >= midi_highest_piano_note){ //piano should be received on these channels
    #ifdef DEBUG_HANDLES
    Serial.print("OFF note2high\t");
    Serial.println(pitch);
    #endif
    return;
  }
  else if(pitch  <  midi_low_nt_ptch_offst){   //not a note this piano can play
    #ifdef DEBUG_HANDLES
    Serial.print("OFF note2low\t");
    Serial.println(pitch);
    #endif
    return;
  }else if(piano_high_notes && (pitch < midi_high_nt_ptch_offst)){ //not a note for the high controller
    #ifdef DEBUG_HANDLES
    Serial.println("OFF note4lowKeys");
    #endif
    return;
  }else if(!piano_high_notes && (pitch >= midi_high_nt_ptch_offst)){
    #ifdef DEBUG_HANDLES
    Serial.println("OFF note4highKeys");
    #endif
    return;
  }
  note_t this_note;
  this_note.pitch = pitch;
  this_note.velocity = velocity;
  #ifdef DEBUG_HANDLES
  Serial.print("N/OFF Buffwrite p ");
  Serial.print(pitch);
  Serial.print(" v ");
  Serial.println(velocity);
  #endif
  if(write_buff(this_note)){
      return;
  } else {
    Serial.println("Buff++"); //buffer is full
      return;
  }
}*/
  /*****
 Purpose: Write to the Ringbuffer
 Parameter List:
         note_str note    This is a note, with the first component being the
                          pitch and the second being velocity
 Return value:
         bool     1 - success
                  0 - buffer full
 *****/
/*bool write_buff(note_t note)
{
  #ifdef DEBUG_BUFF
  Serial.print("BuffWrSt \t");
  Serial.print(bufferLength);
  #endif
  if(bufferLength == SIZE_OF_BUFFER){
    Serial.println("Full Buff");
    return 0;   //Fail: Buffer full
  }
  //Serial.println("In Buffwrite");
  circularBuff[writeIndex] = note.pitch;
  circularBuff[writeIndex + 1] = note.velocity;
  writeIndex = writeIndex + 2;
  bufferLength = bufferLength + 2;
  if(writeIndex == SIZE_OF_BUFFER){
    Serial.println("BuffWr_Wrap");
    writeIndex = 0;
  }
  #ifdef DEBUG_BUFF
  Serial.print("BuffWrEnd \t");
  Serial.println(bufferLength);
  #endif
  return 1;   //Success
}*/
/*****
 Purpose: Read from the Ringbuffer
 Parameter List:
         void
 Return value:
         note_str note    This is a note, with the first component being the
                          pitch and the second being velocity
 *****/
/*note_t read_buff(void)
{
  #ifdef DEBUG_BUFF
  Serial.print("BuffRdSt \t");
  Serial.println(bufferLength);
  #endif
  //Serial.println("In Buffead");
  note_t this_note;
  if(bufferLength == 0){ //should never get here
    Serial.println("Err: Buff 0");
    this_note.pitch = 0;
    this_note.velocity = 0;
    return this_note; //return dummy note
  }
  this_note.pitch = circularBuff[readIndex];
  this_note.velocity = circularBuff[readIndex+1];
  bufferLength = bufferLength - 2;
  readIndex = readIndex + 2;

  if(readIndex == SIZE_OF_BUFFER){ //wrap the buffer
    Serial.println("BuffRd_Wrap");
    readIndex = 0;
  }

  #ifdef DEBUG_BUFF
  Serial.print("\tpitch\t");
  Serial.print(this_note.pitch);
  Serial.print("\tvel\t");
  Serial.println(this_note.velocity);
  Serial.print("BuffRdEnd \t");
  Serial.println(bufferLength);
  #endif
  return this_note;
} */
/*****
  Purpose: Check if the circular buffer is empty
  Parameter List:
        void
  Return value:
        bool  1 - Buffer is empty
              0 - Buffer not empty
 *****/
 /*bool buff_is_empty(void){
  if(bufferLength == 0)
    return 1;
  else
    return 0;
 }*/
 /*****
   Purpose: Check if the circular buffer is empty
   Parameter List:
         void
   Return value:
         void
  *****/
 /*void buff_clr(void){
   bufferLength = 0;
   readIndex = 0;
   writeIndex = 0;
   return;
 }
*/
/*****
  Purpose: This function runs when we have no incoming info on the midiSerial
            stream. It checks the note buffer and writes any out standing
            note on or note off data to the servos
  Parameter List:
        void
  Return value:
        void
 *****/
/*
bool checkOut(void){
    if(buff_is_empty()) //nothing to send to servos
    {
        //Serial.println("No_bf");
        return 0;
    }
    note_t this_note = read_buff();
    byte temp_pitch;

    if(piano_high_notes)
    {
          if(this_note.pitch < midi_high_nt_ptch_offst){ //not a note for this controller
            Serial.println("ChkOut: N2Low");
            return 0;
          }else{ // this_note.pitch must be >= midi_high_nt_ptch_offst
              temp_pitch = (this_note.pitch - midi_high_nt_ptch_offst);
              if(servoWrite(temp_pitch, this_note.velocity)){
                #ifdef DEBUG_SERVO
                Serial.println("Sv_wr_OK");
                #endif
                return 1;
              }
              else{
                Serial.println("Sv_wr_err");
                return 0;
              }
          }
    }else{ //we have a low note
          if(this_note.pitch >= midi_high_nt_ptch_offst){ //not a note for this controller
              Serial.println("ChkOut: N2High");
              return 0;
          }else{
              temp_pitch = this_note.pitch - midi_low_nt_ptch_offst;
              if(servoWrite(temp_pitch, this_note.velocity)){
                #ifdef DEBUG_SERVO
                Serial.println("Sv_wr_OK");
                #endif
                return 1;
              }else{
                Serial.println("Sv_wr_err");
                return 0;
              }
          }
    }
  }*/
/* USED TO BE PART OF checkOut()
      if(pitch >= midi_high_nt_ptch_offst && piano_high_notes == true){
      //  Serial.println("OFF: High Note");
        this_note.pitch = pitch - midi_high_nt_ptch_offst;
        this_note.velocity = 0;
      //  servoWrite(this_note.pitch, this_note.velocity);//write_buff(this_note);
        //write_buff(this_note);
        return;
      }
      else if( pitch >= midi_low_nt_ptch_offst
              && pitch < midi_high_nt_ptch_offst
              && piano_high_notes == false){
        this_note.pitch = pitch - midi_low_nt_ptch_offst;
        this_note.velocity = 0;
        Serial.println("OFF: Low Note");
        //servoWrite(this_note.pitch, this_note.velocity);//write_buff(this_note);
        //write_buff(this_note);
        return;

    {
    note_t note = read_buff();
    servoWrite(note.pitch, note.velocity);
    return;
  }*/

/*****
  Purpose: This function runs when we have no incoming info on the midiSerial
            stream. It checks the note buffer and writes any out standing
            note on or note off data to the servos
  Parameter List:
        void
  Return value:
        void
 *****/
/*
void checkOut(void){
  static int place = 0; //static to stored from the last check
  int count  = 0;       //count how many places we have checked
  byte sv_num = 0;
  while ((storeNote[place] == 0) && (count < buffer_length)){ //look for next note
    place++;
    if(place >= buffer_length){
      place = 0;
    }
    count++;
    if(count == buffer_length) //nothing in the buffer
    {
    //  Serial.println("StoreNote buff empty");
      return;
    }
  }
  if(count < buffer_length){//found the next note to write
    if(piano_high_notes == true){ //Adjust for high/low side of piano
      sv_num = storeNote[place] - midi_high_nt_ptch_offst;
    } else {
      sv_num = storeNote[place] - midi_low_nt_ptch_offst;
    }
    servoWrite(sv_num, storeVel[place]);
      }
   bufferRemove(storeNote[place],storeVel[place]);      // remove from buffer
  }
*/


/*****
  Purpose:     Store current note and velocity, send this when we have time
  Parameter List:
        byte note     which note (servo number)
        byte vel      what is the velocity?
  Return value:
        int         0 success, 1 fail
 *****/
/*int bufferSave(byte note, byte vel){
  //search for a free space
  int place = 0;
  while(storeNote[place] !=(byte)0 && place < buffer_length){
    place++;
  }
  if(place < buffer_length){//found one
    storeNote[place] = note;
    storeVel[place] = vel;
    return 0;
  }else{
    return 1;
  }
}
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

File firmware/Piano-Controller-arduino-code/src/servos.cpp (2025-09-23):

/*
This file holds all the servo related function written
for the Piano Player
 */
#include <Arduino.h>
#include <Servo.h>
#include <EEPROM.h>
#include "servos.h"

//#define SETUPEEPROM
//#define DEBUG_SERVO

Servo my_servo[num_servos];  //An array of servos
#ifdef SETUPEEPROM
/****** HIGH SIDE RESTART TRIM *******/
byte servo_trim_h[] = {140,125,120,135,115,130,115,122, //0 -- 7
                    130,126,130,125,125,120,120,130, // 8 -- 15
                    120,130,125,125,135,138,120,125, //16 -- 23
                    120,140,130,120,130,105,120,120, //24 - 31
                    105,120,130,100,130,130,120,120, // 32 -- 39
                    120,140,115,143
                    }; // 40 - 43
/*******LOW SIDE RESTART EEPROM TRIM ********/
byte servo_trim_l[] = {145,120,140,140,125,130,135,140, //0 -- 7
                      140,130,130,100,130,100,135,130, // 8 -- 15
                      100,125,120,130,125,100,130,110, //16 -- 23
                      120,130,125,140,110,130,100,115, //24 - 31
                      135,100,125,105,135,110,125,125, // 32 -- 39
                      110,125,115,150}; // 40 - 43

#else
byte servo_trim_h[num_servos];
byte servo_trim_l[num_servos];
#endif

//Pointers to arrays
byte *ptr_to_trim;
byte *ptr_to_dir;
const byte *ptr_to_wh_hm;
const byte *ptr_to_bl_hm;
extern volatile byte keyPressed;

/*****
Arduino pins matched to servos
*****/
byte servo_pin[] = { 2,  3,  4,  5,  6,  7,  8,  9,
                    10, 11, 12, 13, 19, 20, 21, 22,
                    30, 29, 28, 27, 26, 25, 24, 23,
                    38, 37, 36, 35, 34, 33, 32, 31,
                    46, 45, 44, 43, 42, 41, 40, 39,
                    53, 52, 51, 50, 49, 48, 47};
 /*****
   Purpose: To Check the trim of the a servo by listening for a keypress using
            a connected microphone.
   Parameter List:
         void
   Return value:
         void
   NOTE: Already run setArrayPointers() so that accounts for high or low notes.
  *****/
void servoTrimInit(void){
  #ifdef DEBUG_SERVO
    Serial.println("Initialising servos");
  #endif
  byte this_trim;
  byte old_trim;
  for(byte i = 0; i < num_servos; i++)
  {
    this_trim = *(ptr_to_trim + i);
    old_trim = this_trim;
    #ifdef DEBUG_SERVO
      Serial.print("Servo: ");
      Serial.print(i);
      Serial.print("bef trim: ");
      Serial.print(this_trim);
    #endif
    my_servo[i].attach(servo_pin[i]);    //attach to current servo
  //  my_servo[i].write(this_trim);
    keyPressed = LOW;  //reset for next interrupt
    //if(*(ptr_to_dir + i) == 1){ //Playing a white note, to press key --angle
    //  this_trim = this_trim + 15;
      if(this_trim > 170) this_trim = 170;
      while (keyPressed == LOW){
         #ifdef DEBUG_SERVO
           Serial.print("Keypress while loop servo ");
           Serial.print(i);
           Serial.print( " ");
           Serial.println(this_trim);
         #endif
        this_trim--;    //increment servo 1 deg until a note sounds
        if(this_trim == 0 || (this_trim == (old_trim - 65)))
          this_trim = old_trim + 20; //try again
        my_servo[i].write(this_trim);
        delay(30);
        }
        this_trim = this_trim - soft_angle; //retract servo by the softpress angle, but trim + soft_angle should make a note.
        my_servo[i].write(this_trim + 10); //this is to avoid the whole device inching upwards through the calibration
        delay(500);
        my_servo[i].detach();
    //} else if(*(ptr_to_dir + i) == 0){ //Playing a black note, to press a key ++ angle
      //  this_trim = this_trim;
      /*  if(this_trim < 10) this_trim = 10;
        while (keyPressed == LOW){
          // #ifdef DEBUG_SERVO
          //   Serial.print("Black while loop");
          //   Serial.println(this_trim);
          // #endif
          this_trim++;    //increment servo 1 deg until a note sounds
          my_servo[i].write(this_trim);
          delay(20);
        }
          this_trim = this_trim - 20; //retract servo by 15 degrees

      }*/
      #ifdef DEBUG_SERVO
        Serial.print("\tafter: ");
        Serial.println(this_trim);
      #endif
      *(ptr_to_trim + i) = this_trim;
      EEPROM.update(i, this_trim);
      //delay(1000);

    }
}
 /*****
       Purpose: Copy EEPROM trim values into sram.
                Point the controller to the correct arrays of trim and direction
               dependant on high notes or low notes
       Parameter list:
               bool hNotes    Is this the high note controller?
               int *ptr_t     Pointer to the 0th value of the trim array
               int *ptr_d     Pointer to the 0th value of the direction array
       Return value:
             void
 *****/
 void setArrayPointers(boolean h_notes)
 {
   if(h_notes)
   {
     ptr_to_trim = servo_trim_h;
   }else{
     ptr_to_trim = servo_trim_l;
   }

   #ifdef DEBUG_SERVO
   Serial.print("\nin setArrayPointers ");
   Serial.println(h_notes);
   #endif

      #ifdef SETUPEEPROM
      for(byte i = 0; i < num_servos; i++){
        EEPROM.update(i, byte(*(ptr_to_trim + i)));
        #ifdef DEBUG_SERVO
        Serial.print("S");
        Serial.print(i);
        Serial.print(" a-");
        Serial.println(int(*(ptr_to_trim + i)));
        #endif
      }
      #endif
      Serial.println("Reading from EEPROM");
      #ifndef SETUPEEPROM
       for(byte i = 0; i < num_servos; i++){
        if(h_notes){
          servo_trim_h[i] = EEPROM.read(i);
          #ifdef DEBUG_SERVO
          Serial.print("Servo number ");
          Serial.print(i);
          Serial.print(" angle is ");
          Serial.println(servo_trim_h[i]);
          #endif
        }else{
          servo_trim_l[i] = EEPROM.read(i);
          #ifdef DEBUG_SERVO
          Serial.print("Servo number ");
          Serial.print(i);
          Serial.print(" angle is ");
          Serial.println(servo_trim_l[i]);
          #endif
        }


       }
       #endif



    /*  if(h_notes == true){
        ptr_to_dir   = servo_high_dir;
      } else{
        ptr_to_dir   = servo_low_dir;
      }
      */

 }
/*****
      Purpose: Attach to all servos in the Servo array send them to the Home
                position
      Parameter list:
              void
      Return value:
            void
*****/
void servoAttach(void){
   for(byte i = 0; i < num_servos; i++){
      my_servo[i].attach(servo_pin[i]);
      my_servo[i].write((*(ptr_to_trim + i)) + retract_angle);
      delay(30); //not sure if the servo library waits for the servo to finish moving
  }
}
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

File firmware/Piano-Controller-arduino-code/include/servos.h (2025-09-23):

#ifndef SERVOS_H
#define SERVOS_H

#include <Arduino.h>
#include <Servo.h>

/******************************************************
Function declarations related to servo setup and control
******************************************************/
void servoAttach(void);
void servoTrimInit(void);
bool isWhiteNote(byte *ptr_sv_dir, int sv_num);
//void servosHome(void);
//int servoTrim(void);
byte servoVelToAngle(int vel, bool is_white);
bool servoWrite(byte sv_num, byte velocity);
//void servoWrite(int note, int velocity, Servo *ptr_sv);
//void servosHome(void);
//void myWriteServo(Servo*, int, int );
void servoHome(int sv_num);
void servoHome(void);
//void servoHome(int off_ang, Servo *ptr_sv); //for all servos
void setArrayPointers(bool);
int servoPosition(int angle, int sv_num);

//Angles for respective velocities
static const byte soft_vel = 60; //maximum "soft" value 128/3
static const byte med_vel  = 90; //maximum "medium" value 128/3*2
static const byte max_vel = 127;   //maximum midi velocity

static const byte soft_angle = -15;
static const byte med_angle = -16;
static const byte hard_angle = -17;
static const byte retract_angle = 0;
//The number of servos we need to control 44 max
static const int num_servos =44;
#endif

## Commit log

2025-09-23 Remove nested git repo reference for firmware
    [3mm - 1 - Mark de Villeirs acrylic.dxf, 3mm - 2 - Mark de Villiers acrylic.dxf, 3mm - 3 - Mark de Villiers acrylic.dxf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]
2025-09-24 Add 1-octave piano bedplate; daily notes
    [Piano_Modular_Frame.FCStd, Servo_sensor_assembly.FCStd]
2025-09-26 feat: add servo plate with bosses/slots, update piano bed with lightening holes, start white servo bar; add 20250925 progress notes
    [Piano_Modular_Frame.FCStd]
2025-10-09 Committing changes to the mechanical redesign for 3D printing
    [Piano_Modular_Frame.FCStd, Prt_+Servo+Assembly_Push+Shaft.stp, Prt_+Servo+Assembly_Servo-shaft+connector.stp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]
